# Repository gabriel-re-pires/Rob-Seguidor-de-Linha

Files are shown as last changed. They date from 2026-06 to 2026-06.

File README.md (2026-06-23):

# Carrinho Seguidor de Linha — Versão ESP32 + Controle de XBOX

Robô seguidor de linha usando sensores infravermelhos, com função adicional de controlar por um controle de Xbox Series X via Bluetooth (estilo *Forza*: gatilhos aceleram/freiam e o analógico esquerdo esterça).

Projeto feito para atividade *Hands-On de Robótica* da disciplina de
**Robótica Aplicada** (Engenharia de Computação — Prof. Milton Miranda Neto).

<p align="center">
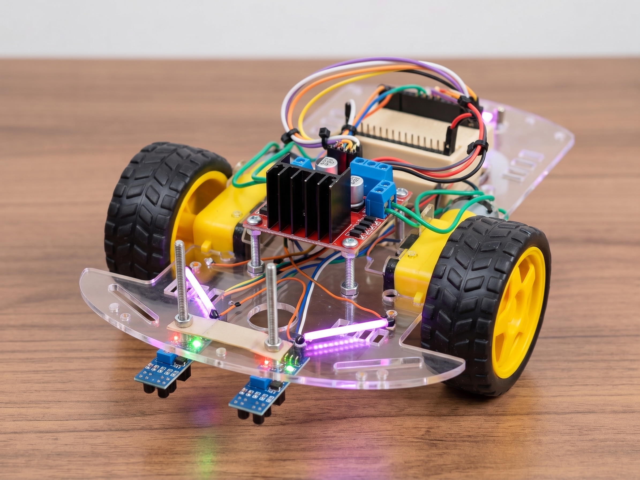
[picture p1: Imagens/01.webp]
Carrinho seguidor de linha - vista 1
  
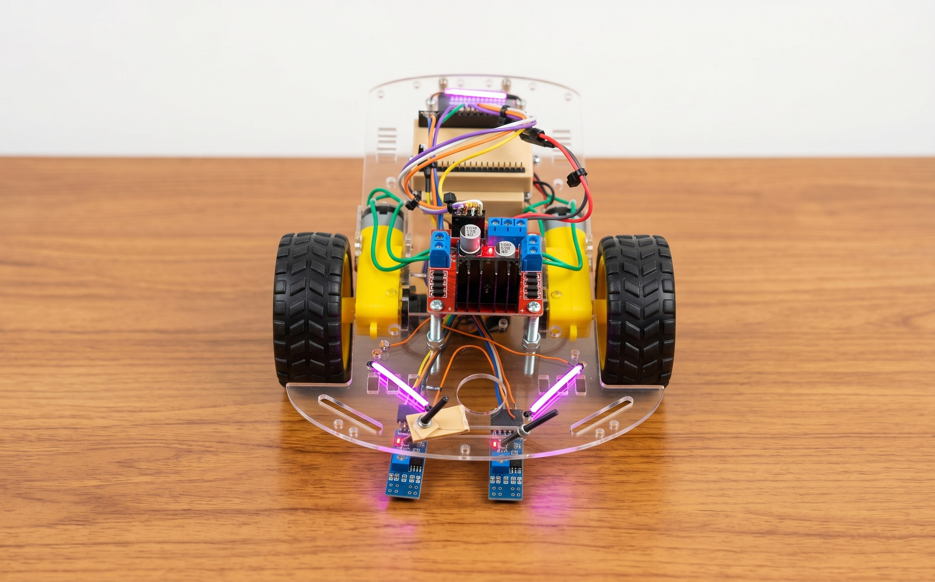
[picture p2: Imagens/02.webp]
Carrinho seguidor de linha - vista 2
  
</p>

---

## Mudanças em relação ao modelo original

| Item | Kit padrão da aula | **Esta versão** |
|---|---|---|
| Cérebro | Arduino Uno (5 V) | **ESP32** (3,3 V, Wi-Fi + Bluetooth) |
| Alimentação | 4× pilhas AA (6 V) | **2× células 3,7 V Li-ion** (reaproveitadas de um *vape* descartado) em série ≈ 7,4 V |
| Carregamento | Trocar pilhas | **2× módulos TP4056** ligados em série (recarga via USB) |
| Controle manual | — | **Joystick Xbox Series X** por Bluetooth (modo *Forza*) |
| Driver dos motores | L298N usando ENA/ENB | **L298N sem ENA/ENB** — o PWM vai direto nos pinos IN |
| Extras | — | **Farol de LED** liga/desliga pelo controle |
| Estrutura | Chassi do kit | Chassi + **cases impressas em 3D** (ESP32 e bateria) |

---

## Funcionamento

O firmware tem **dois modos**, alternados pelo botão **Y** do controle:

### 1. Modo Autônomo 
Lê os dois sensores TCRT5000 e decide o movimento:

> **HIGH = sensor sobre a linha preta** · **LOW = sensor sobre o chão claro**

| Sensor Esq. | Sensor Dir. | Situação | Ação |
|:---:|:---:|---|---|
| HIGH | HIGH | Ambos na linha → **marca de parada** | Para, dá uma ré curtinha e fica parado 3 s |
| LOW  | HIGH | Linha só à direita | Gira para a **direita** |
| HIGH | LOW  | Linha só à esquerda | Gira para a **esquerda** |
| LOW  | LOW  | Nenhum na linha | Segue **em frente** |

### 2. Modo Manual 
Pressione **Y** para usar o controle:

- **Gatilho RT** → acelera para frente
- **Gatilho LT** → ré / freio
- **Analógico esquerdo (eixo X)** → esterçamento (vira para os lados)
- **Botão X** → liga/desliga o **farol** de LED (funciona nos dois modos)
- **Botão Y** → alterna entre Manual e Autônomo

A mistura de aceleração + direção é feita por *differential drive*:

## Hardware

| Componente | Qtd. | Função |
|---|:----:|---|
| ESP32 DevKit | 1 | Microcontrolador (cérebro) |
| Ponte H L298N | 1 | Driver de potência dos motores |
| Motor DC com redutor + roda | 2 | Tração traseira |
| Rodízio (roda boba) | 1 | Apoio dianteiro |
| Sensor TCRT5000 (IR) | 2 | Detecção da linha |
| Célula Li-ion 3,7 V | 2 | Alimentação (em série ≈ 7,4 V) |
| Módulo carregador TP4056 | 2 | Recarga das células (em série) |
| LEDs (farol) | 1+ | Iluminação frontal |
| Chassi + cases 3D | — | Estrutura |

### Pinagem (ESP32)

| Sinal | GPIO | Observação |
|---|:----:|---|
| L298N **IN1** (Motor Esq.) | 27 | PWM de direção/velocidade |
| L298N **IN2** (Motor Esq.) | 26 | PWM de direção/velocidade |
| L298N **IN3** (Motor Dir.) | 25 | PWM de direção/velocidade |
| L298N **IN4** (Motor Dir.) | 33 | PWM de direção/velocidade |
| Sensor IR **Esquerdo** (OUT) | 34 | *Input-only* no ESP32 |
| Sensor IR **Direito** (OUT) | 35 | *Input-only* no ESP32 |
| **Farol** (LEDs) | 4 | Saída digital |

O passo a passo completo de montagem e ligação está em
**[`Montagem/`](Montagem/)**.

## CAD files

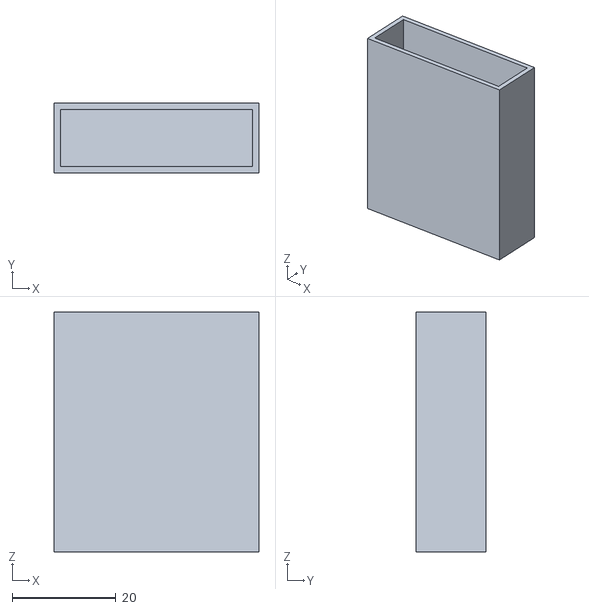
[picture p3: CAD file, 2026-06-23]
Print3D/CaseBat.stl
39.4 x 13.4 x 46.2

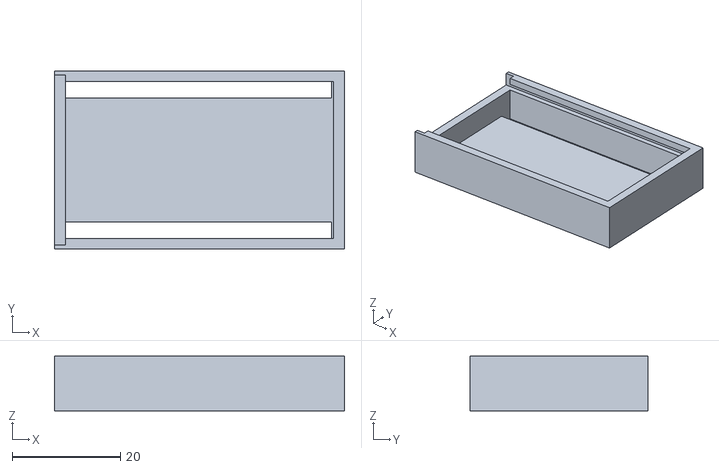
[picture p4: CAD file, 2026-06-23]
Print3D/CaseEsp32.stl
53.5 x 32.9 x 10.1

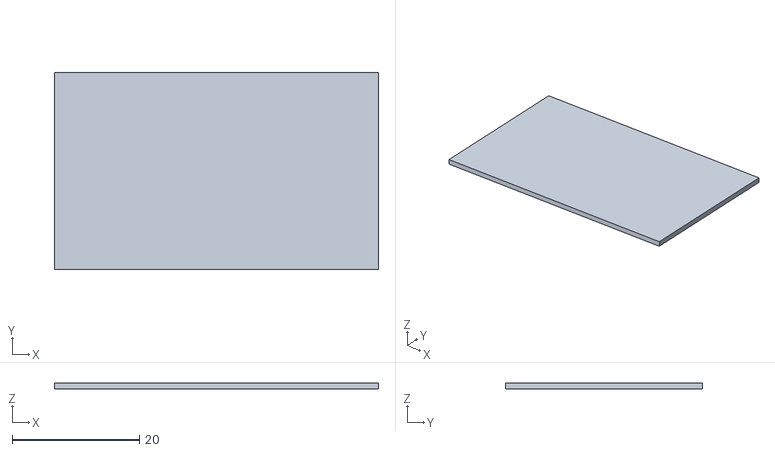
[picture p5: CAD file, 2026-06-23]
Print3D/CaseEsp32Tampa.stl
50.9 x 30.9 x 1.00

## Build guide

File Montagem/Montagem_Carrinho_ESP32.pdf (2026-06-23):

# Guia de Montagem e Ligacao

### Carrinho Seguidor de Linha - Versao ESP32

Este guia descreve a montagem do carrinho seguidor de linha na versao melhorada com ESP32, controle Xbox sem fio, farol de LED e bateria de ion-litio recarregavel. Ele complementa a apostila original da aula (robotica_carrinho_seguidor.pdf), mas a pinagem e a eletronica aqui sao as desta versao - diferentes do kit padrao com Arduino Uno.

ATENCAO: mantenha a alimentacao desligada e o cabo USB desconectado durante toda a fiacao. Confira a polaridade duas vezes - inverter VCC/GND queima o L298N ou o ESP32.

## 1. Lista de componentes

Componente | Qtd. | Funcao
ESP32 DevKit | 1 | Microcontrolador (cerebro)
Ponte H L298N | 1 | Driver de potencia dos motores
Motor DC com redutor + roda | 2 | Tracao traseira
Rodizio (roda boba dianteira) | 1 | Apoio frontal
Sensor infravermelho TCRT5000 | 2 | Deteccao da linha preta
Celula Li-ion 3,7 V (de vape) | 2 | Alimentacao
Modulo carregador TP4056 | 2 | Recarga das celulas
LED(s) p/ farol + resistor | 1+ | Iluminacao frontal
Chave liga/desliga | 1 | Corte de energia
Cases impressas em 3D | - | Estrutura/fixacao (ESP32 + bateria)
Jumpers, parafusos M3, espacadores | - | Conexoes e fixacao

Ferramentas: chave Phillips pequena, chave de fenda (bornes do L298N), alicate de bico fino, ferro de solda, multimetro.

## 2. Montagem mecanica

1. Motores: fixe os dois motores DC nas laterais traseiras do chassi, com o eixo apontando para fora. Aperte os parafusos M3 sem forcar. Deixe os fios saindo para o interior do chassi.
2. Rodizio dianteiro: parafuse a roda boba no furo frontal. Ela deve girar livre em qualquer direcao.
3. Rodas: encaixe as rodas amarelas direto no eixo dos motores (o chanfro trava a roda). O carrinho deve ficar nivelado nas 3 rodas.
4. Sensores IR na frente: fixe os dois TCRT5000 na dianteira, voltados para o chao, a 1-2 cm de altura. Sensor esquerdo a esquerda da linha, direito a direita, espacados ~2-3 cm.
5. Cases 3D: fixe a case do ESP32 e a case da bateria no chassi (arquivos em Print3D/). Elas organizam a eletronica e protegem as celulas.

Carrinho Seguidor de Linha - Versao ESP32 | Guia de Montagem e Ligacao

## 3. Alimentacao - bateria Li-ion + 2x TP4056

Esta versao nao usa pilhas AA. A alimentacao e feita por duas celulas Li-ion de 3,7 V (reaproveitadas de um vape Ignite usado), ligadas em serie para fornecer ~7,4 V aos motores e ao regulador do L298N. A recarga e feita por dois modulos TP4056, um para cada celula.

+7,4V (para VCC do L298N)
^
[ Celula B 3,7V ] -- TP4056 (B) |---------- ponto central (3,7V) [ Celula A 3,7V ] -- TP4056 (A)
v
GND (para GND do L298N)

CUIDADO com Li-ion em serie: o TP4056 e um carregador de 1 celula. Carregue/monitore cada celula com seu proprio TP4056 e evite descarregar abaixo de ~3,0 V por celula. Celulas de vape nao tem BMS -manuseie com atencao (curto/sobreaquecimento sao perigosos). Use celulas com tensoes e capacidades parecidas.

Ligacao | Origem | Destino
+7,4 V (positivo da serie) | terminal + da bateria | VCC do L298N
GND | terminal - da bateria | GND do L298N
Recarga | USB do TP4056 | uma celula cada

Mantenha o jumper J1 do L298N instalado (entrada < 12 V) - assim o regulador interno de 5 V do L298N fica ativo para alimentar o ESP32.

## 4. Ligacao do driver L298N

### 4.1 Motores e alimentacao

Borne / Pino do L298N | Conectar em | Observacao
OUT1 / OUT2 | Motor Esquerdo | Se girar ao contrario, inverta os 2 fios
OUT3 / OUT4 | Motor Direito | Idem
VCC | +7,4 V da bateria | Alimentacao dos motores
GND | GND da bateria e do ESP32 | GND comum e obrigatorio
+5V (saida regulada) | Pino 5V/VIN do ESP32 | Alimenta o ESP32 pela bateria

### 4.2 Jumpers ENA / ENB - mantenha-os instalados

Nesta versao o ESP32 NAO controla ENA/ENB. Os jumpers de enable ficam instalados (canais sempre habilitados) e o PWM e aplicado diretamente nos pinos IN1-IN4. Ou seja, velocidade e direcao dos motores saem todas dos pinos IN.

### 4.3 Controle (ESP32 -> L298N)

GPIO do ESP32 | Pino do L298N | Funcao
27 | IN1 | Motor Esquerdo - PWM (sentido + velocidade)
26 | IN2 | Motor Esquerdo - PWM (sentido + velocidade)
25 | IN3 | Motor Direito - PWM (sentido + velocidade)
33 | IN4 | Motor Direito - PWM (sentido + velocidade)

Como o codigo aciona cada motor (funcao acionarMotores):

Movimento da roda | Pino A | Pino B
Frente | 0 | PWM (velocidade)
Re | PWM (velocidade) | 0
Parar (freio) | 255 | 255

Os dois pinos em 255 colocam o canal em freio (ambos em nivel alto), segurando a roda parada.

## 5. Sensores infravermelhos TCRT5000

Pino do sensor | Conectar em | Observacao
VCC | 3V3 (ou 5V) do ESP32 | Alimentacao
GND | GND comum | Mesmo barramento do L298N/ESP32
OUT - sensor Esquerdo | GPIO 34 | Input-only no ESP32
OUT - sensor Direito | GPIO 35 | Input-only no ESP32

CONVENCAO DESTA VERSAO (importante - diferente da apostila):
HIGH = sensor sobre a LINHA PRETA | LOW = sensor sobre o chao claro

Cada TCRT5000 tem um trimpot (potenciometro azul) para ajustar a sensibilidade. Calibracao:
1. Sobre o chao claro, ambos os sensores devem ler LOW.
2. Sobre a linha preta, o sensor deve ler HIGH.
3. Gire o trimpot ate obter essa resposta; use o LED indicador do modulo como guia.
4. Altura ideal: 5 mm a 15 mm do chao.

Se o comportamento ficar invertido (carrinho foge da linha), confira esta convencao HIGH/LOW e/ou os trimpots antes de mexer no codigo.

## 6. Farol de LED

Ligacao | Destino
Anodo do(s) LED(s) via resistor | GPIO 4 do ESP32
Catodo | GND comum

O farol liga/desliga pelo botao X do controle Xbox (funciona nos dois modos). Use um resistor adequado (ex.: 220-330 ohm) em serie com o LED.

## 7. Controle Xbox (modo manual)

O modo manual usa um joystick Xbox Series X por Bluetooth, via biblioteca XboxSeriesXControllerESP32_asukiaaa. E preciso informar o MAC Address do controle no codigo:

XboxSeriesXControllerESP32_asukiaaa::Core
xboxController("Coloque_o_MAC_Qui");
Comando do controle | Acao
Botao Y | Alterna Manual <-> Autonomo
Botao X | Liga/desliga o farol
Gatilho RT | Acelera para frente
Gatilho LT | Re / freio
Analogico esquerdo (eixo X) | Estercamento (vira)

Se o controle desconectar no modo manual, o carrinho volta sozinho para o modo Seguir Linha.

## 8. Checklist final antes de ligar

- [ ] Motores nos bornes OUT1/OUT2 (esq.) e OUT3/OUT4 (dir.).
- [ ] Bateria: +7,4 V -> VCC do L298N; GND -> GND do L298N.
- [ ] GND comum entre bateria, L298N e ESP32.
- [ ] 5V do L298N -> pino 5V/VIN do ESP32 (jumper J1 instalado).
- [ ] Jumpers ENA/ENB do L298N instalados.
- [ ] GPIO 27, 26, 25, 33 -> IN1, IN2, IN3, IN4.
- [ ] Sensor esq. OUT -> GPIO 34; sensor dir. OUT -> GPIO 35 (VCC/GND ligados).
- [ ] Farol no GPIO 4 com resistor.
- [ ] Sensores calibrados (LINHA = HIGH, CHAO = LOW).
- [ ] Nenhum fio solto, nenhum borne mal apertado.
- [ ] MAC do controle preenchido no codigo.

Tudo conferido? Ligue, posicione o carrinho na pista e divirta-se!

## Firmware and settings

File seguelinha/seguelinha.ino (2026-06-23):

#include <XboxSeriesXControllerESP32_asukiaaa.hpp>

// O MAC Address do teu Xbox Wireless Controller
XboxSeriesXControllerESP32_asukiaaa::Core xboxController("Coloque_o_MAC_Qui");

// --- Pinos da Ponte H L298N (SEM ENA E ENB) ---
const int pinoIN1 = 27;
const int pinoIN2 = 26;
const int pinoIN3 = 25;
const int pinoIN4 = 33;

// --- Pinos dos Sensores TCRT5000 ---
const int pinoSensorEsq = 34;
const int pinoSensorDir = 35;

// --- Pino dos filamentos de LEDs ---
const int pinoFarol = 4;

// --- Variáveis de Estado ---
bool modoManual = false;
bool estadoBotaoYAnterior = false;
bool estadoFarol = false;
bool estadoBotaoXAnterior = false;

void setup() {
  Serial.begin(115200);
  pinMode(pinoIN1, OUTPUT);
  pinMode(pinoIN2, OUTPUT);
  pinMode(pinoIN3, OUTPUT);
  pinMode(pinoIN4, OUTPUT);
  pinMode(pinoSensorEsq, INPUT);
  pinMode(pinoSensorDir, INPUT);
  pinMode(pinoFarol, OUTPUT);
  digitalWrite(pinoFarol, LOW);
  pararMotores();
  xboxController.begin();
}

void loop() {
  xboxController.onLoop();
  if (xboxController.isConnected()) {
    // --- LÓGICA DO BOTÃO Y (Alternar Modos) ---
    bool apertouY = xboxController.xboxNotif.btnY;
    if (apertouY && !estadoBotaoYAnterior) {
      modoManual = !modoManual;
      pararMotores();
    }
    estadoBotaoYAnterior = apertouY;

    // --- LÓGICA DO BOTÃO X (Ligar/Desligar Farol) ---
    bool apertouX = xboxController.xboxNotif.btnX;
    if (apertouX && !estadoBotaoXAnterior) {
      estadoFarol = !estadoFarol;
      digitalWrite(pinoFarol, estadoFarol ? HIGH : LOW);
    }
    estadoBotaoXAnterior = apertouX;

    // --- EXECUÇÃO DOS MODOS ---
    if (modoManual) {
      controleForzaXbox();
    } else {
      seguirLinha();
    }
  } else {
    if (modoManual == true) {
      modoManual = false;
      pararMotores();
    }
    seguirLinha();
  }
}

// --- LÓGICA DO CONTROLE XBOX (ESTILO FORZA) ---
void controleForzaXbox() {
  uint16_t gatilhoRT = xboxController.xboxNotif.trigRT;
  uint16_t gatilhoLT = xboxController.xboxNotif.trigLT;
  uint16_t eixoX_raw = xboxController.xboxNotif.joyLHori;

  int forcaFrente = map(gatilhoRT, 0, 1023, 0, 255);
  int forcaRe = map(gatilhoLT, 0, 1023, 0, 255);
  int aceleracaoTotal = forcaFrente - forcaRe;
  int direcao = map(eixoX_raw, 0, 65535, -255, 255);
  if (abs(direcao) < 50) {
    direcao = 0;
  }
  int velEsq = aceleracaoTotal - direcao;
  int velDir = aceleracaoTotal + direcao;
  velEsq = constrain(velEsq, -255, 255);
  velDir = constrain(velDir, -255, 255);
  acionarMotores(velEsq, velDir);
}

// Convenção: HIGH = sensor está vendo a linha preta / LOW = chão.
void seguirLinha() {
  int valE = digitalRead(pinoSensorEsq);
  int valD = digitalRead(pinoSensorDir);

  // ======================================================================
  // TUNING
  // ======================================================================
  int velEsqReta = 80;   // velocidade da roda esquerda na reta
  int velDirReta = 95;   // velocidade da roda direita na reta
  int velGiro    = 100;  // velocidade ao virar
  // ======================================================================

  // CASO 1: os DOIS sensores na linha -> marca de PARADA.
  if (valE == HIGH && valD == HIGH) {
    acionarMotores(0, 0);
    delay(300);
    acionarMotores(-velEsqReta, -velDirReta);   // ré curtinha
    delay(150);
    acionarMotores(0, 0);
    delay(3000);
  }
  // CASO 2: só o sensor DIREITO na linha -> vira para a DIREITA.
  else if (valD == HIGH) {
    acionarMotores(velGiro, -velGiro);
  }
  // CASO 3: só o sensor ESQUERDO na linha -> vira para a ESQUERDA.
  else if (valE == HIGH) {
    acionarMotores(-velGiro, velGiro);
  }
  // CASO 4: nenhum sensor na linha -> segue em frente.
  else {
    acionarMotores(velEsqReta, velDirReta);
  }
}

// --- FUNÇÃO MESTRE DOS MOTORES ---
void acionarMotores(int velEsq, int velDir) {
  // Roda Esquerda
  if (velEsq > 0) {
    analogWrite(pinoIN1, 0);
    analogWrite(pinoIN2, abs(velEsq));
  } else if (velEsq < 0) {
    analogWrite(pinoIN1, abs(velEsq));
    analogWrite(pinoIN2, 0);
  } else {
    analogWrite(pinoIN1, 255);
    analogWrite(pinoIN2, 255);
  }
  // Roda Direita
  if (velDir > 0) {
    analogWrite(pinoIN3, abs(velDir));
    analogWrite(pinoIN4, 0);
  } else if (velDir < 0) {
    analogWrite(pinoIN3, 0);
    analogWrite(pinoIN4, abs(velDir));
  } else {
    analogWrite(pinoIN3, 255);
    analogWrite(pinoIN4, 255);
  }
}

void pararMotores() {
  acionarMotores(0, 0);
}
